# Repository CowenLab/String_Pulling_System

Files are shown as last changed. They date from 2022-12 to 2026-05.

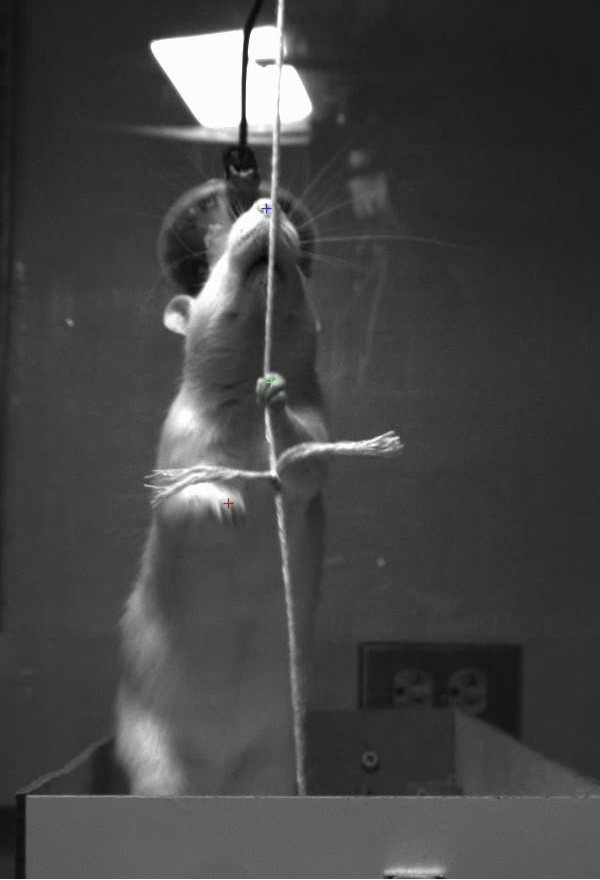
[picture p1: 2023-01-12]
Original_instructions_from_Jordan_thesis/Code/Video Processing/DeepLabCut/labeled-data/Vertical17.2_labeled/img121300.png

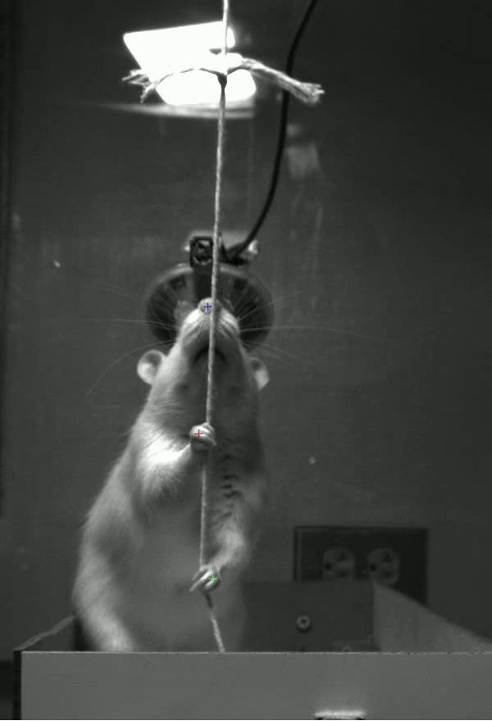
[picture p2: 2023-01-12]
Original_instructions_from_Jordan_thesis/Code/Video Processing/DeepLabCut/labeled-data/Vertical17.2_labeled/img121060.png

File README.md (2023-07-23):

# Pulling and Neural Data Analysis (PANDA) String Pulling System
Developed in the Cowen Laboratory.
See... [biorxiv](https://www.biorxiv.org/content/10.1101/2023.07.02.547431v1)

## Folders
* Hardware Manuals: Contains Manufacturer manuals of components. Currently it just has an entry for the Mako camera.
* src/arduino: Contains source code for controlling the string pulling apparatus.
** rotary_encoder: Arduino code for controlling the rotary encoder and experiment control for the single-arduino system
** rotary_encoder_two: Arduino code for controlling the rotary encoder and experiment control for the dual-arduino system (in Supplementary Information)
** experiment_control: Arduino code for the experiment control Arduino that controls the feeder in addition to tracking pull distance.. This code can handle 2 encorders (e.g., if you had 2 strings)
** experiment_control_single_encoder: As above but for a single encoder (string).
* src/matlab: Contains source code for analysis of string pulling data.
* 3d_print_and_laser_cut_files: files for printing the camera mount and pully wheels
* String_Pull_Training: Notes and logs from training specific animals on the task.
* Instructions: Additional technical instructions for building the system and for setting up the camera.
* Original_instructions_from_Jordan_thesis: Legacy data from Gianna Jordan's Masters thesis on the string pulling system.
* Videos: videos of rats performing the task.

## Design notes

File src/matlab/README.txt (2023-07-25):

This is a self-contained demo showing how to sync data with a neural recording system and how to segment front-paw video data from deep lab cut into different phases of reaching/pulling.
Make sure all files here are in your matlab path and run the demo from this directory.

The only file you need to run is SPG_demo_process_DLC_data.m

-Cowen 2023

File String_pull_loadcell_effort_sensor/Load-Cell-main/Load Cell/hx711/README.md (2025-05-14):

# HX711: Python class for the HX711 load cell

This is a very short and simple class. This lib includes three variants of the
module. One is using direct GPIO pin handling, the other uses the PIO
module of the RPI Pico. The third variant uses SPI.
Besides the class instantiation, all variants offer the same methods.
The preferred variants are GPIO and PIO, because they deal properly with the conversion
ready signal resulting in a more precise result.

## Constructor

### hx711 = HX711(clock_pin, data_pin, gain=128)

This is the GPIO constructor. data_pin and clock_pin are the pin objects
of the GPIO pins used for the communication. clock_pin must not be an input-only pin.
gain is the setting of gain and channel of the load cell amplifier.
The default value of 128 also selects channel A.

### hx711 = HX711(clock_pin, data_pin, gain=128, state_machine=0)

This is the Raspberry Pi PIO constructor. data_pin and clock_pin are the pin objects
of the GPIO pins used for the communication. 
gain is the setting of gain and channel of the load cell amplifier.
The default value of 128 also selects channel A.
The argument state_machine has to be set to different values if more than one
HX711 device is used by an application.

### hx711 = HX711(clock_pin, data_pin, spi, gain=128)

This is the SPI constructor. data_pin is the SPI MISO, clock_pin the SPI MOSI. These must be
Pin objects, with data_pin defined for input, clock_pin defined as output. They must be supplied
in addition to the spi object, even if spi uses the same  pins for miso and mosi.
spi is the SPI object. The spi clock signal will not be be used.
gain is the setting of gain and channel of the load cell amplifier.
The default value of 128 also selects channel A.

## Methods

### hx711.set_gain(gain)

Sets the gain and channel configuration which is used for the next call of hx711.read()

|Gain|Channel|
|:-:|:-:|
|128|A|
|64|A|
|32|B|

### result = hx711.read()

Returns the actual raw value of the load cell. Raw means: not scaled, no offset
compensation.

### result = hx711.read_average(times=3)

Returns the raw value of the load cell as the average of times readings of The
raw value.

### result = hx711.read_lowpass()

Returns the actual value of the load cell fed through an one stage IIR lowpass
filter. The properties of the filter can be set with set_time_constant().

### rh = hx711.set_time_constant(value=None)

Set the time constant used by hx711.read_lowpass(). The range is 0-1.0. Smaller
values means longer times to settle and better smoothing.
If value is None, the actual value of the time constant is returned.

### value = hx711.get_value()

Returns the difference of the filtered load cell value and the offset, as set by hx711.set_offset() or hx711.tare()

### units = hx711.get_units()

Returns the value delivered by hx711.get_value() divided by the scale set by
hx711.set_scale().

### hx711.tare(times=15)

Determine the tare value of the load cell by averaging times raw readings.

### hx711.power_down()

Set the load cell to sleep mode.

### hx711.power_up()

Switch the load cell on again.

## Examples

```
# Example for Pycom device, gpio mode
# Connections:
# Pin # | HX711
# ------|-----------
# P9    | data_pin
# P10   | clock_pin
#

from hx711_gpio import HX711
from machine import Pin

pin_OUT = Pin("P9", Pin.IN, pull=Pin.PULL_DOWN)
pin_SCK = Pin("P10", Pin.OUT)

hx711 = HX711(pin_SCK, pin_OUT)

hx711.tare()
value = hx711.read()
value = hx711.get_value()
```

```
# Example for micropython.org device, gpio mode
# Connections:
# Pin # | HX711
# ------|-----------
# 12    | data_pin
# 13    | clock_pin
#

from hx711_gpio import HX711
from machine import Pin

pin_OUT = Pin(12, Pin.IN, pull=Pin.PULL_DOWN)
pin_SCK = Pin(13, Pin.OUT)

hx711 = HX711(pin_SCK, pin_OUT)

hx711.tare()
value = hx711.read()
value = hx711.get_value()
```

```
# Example for micropython.org device, RP2040 PIO mode
# Connections:
# Pin # | HX711
# ------|-----------
# 12    | data_pin
# 13    | clock_pin
#

from hx711_pio import HX711
from machine import Pin

pin_OUT = Pin(12, Pin.IN, pull=Pin.PULL_DOWN)
pin_SCK = Pin(13, Pin.OUT)

hx711 = HX711(pin_SCK, pin_OUT, state_machine=0)

hx711.tare()
value = hx711.read()
value = hx711.get_value()
```

```
# Example for Pycom device, spi mode
# Connections:
# Pin # | HX711
# ------|-----------
# P9    | data_pin
# P10   | clock_pin
# None  | spi clock
#

from hx711_spi import HX711
from machine import Pin, SPI

pin_OUT = Pin("P9", Pin.IN, pull=Pin.PULL_DOWN)
pin_SCK = Pin("P10", Pin.OUT)

spi = SPI(0, mode=SPI.MASTER, baudrate=1000000, polarity=0,
             phase=0, pins=(None, pin_SCK, pin_OUT))

hx = HX711(pin_SCK, pin_OUT, spi)

hx711.tare()
value = hx711.read()
value = hx711.get_value()
```

```
# Example for micropython.org device, spi mode
# Connections:
# Pin # | HX711
# ------|-----------
# 12    | data_pin
# 13    | clock_pin
# 14    | spi clock

from hx711_spi import HX711
from machine import Pin

pin_OUT = Pin(12, Pin.IN, pull=Pin.PULL_DOWN)
pin_SCK = Pin(13, Pin.OUT)
spi_SCK = Pin(14)

spi = SPI(1, baudrate=1000000, polarity=0,
          phase=0, sck=spi_SCK, mosi=pin_SCK, miso=pin_OUT)

hx = HX711(pin_SCK, pin_OUT, spi)

hx711.tare()
value = hx711.read()
value = hx711.get_value()
```

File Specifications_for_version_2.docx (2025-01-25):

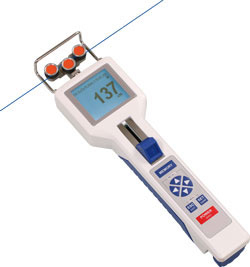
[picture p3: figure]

- Integrated tensiometer that does not add much string resistance. Wire resistance design.
  - https://www.futek.com/applications/Wire-Tension-Meter
  - https://www.futek.com/applications/Wire-Tension-Measurement
  - DTS Hand-Held Digital Tension Meter
- Capacity for 2 strings side-by-side.
- 2 levers also to the side.
- Food port integrated. Solenoid.
- Laser sensors for approach and food port.
- Integrated tracking with camera.
- Arduino or pico?
- Clear TTLs for sync with neural data.
- Integration with 28V Med Associates system.- I want an independent interface that connects med associates levers to any Arduino—just send out 5V pulses to extend/retract and just get 5V pulses (isolated) for when a lever is pressed. General purpose and will plug into any med associates lever system – one per lever – nothing complicated. Maybe smaller isolators? Noise Free.
- Simple laser-cut holder for string. All designs in Fusion 360.
- Simple and documented code.
- Ultimately – would like 3 such systems.

Other

- A way to incorporate a ‘ratchet’ so that the string only turns in one direction to train a novel movement direction.
- A way to angle the string?

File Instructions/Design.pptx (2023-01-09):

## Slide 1

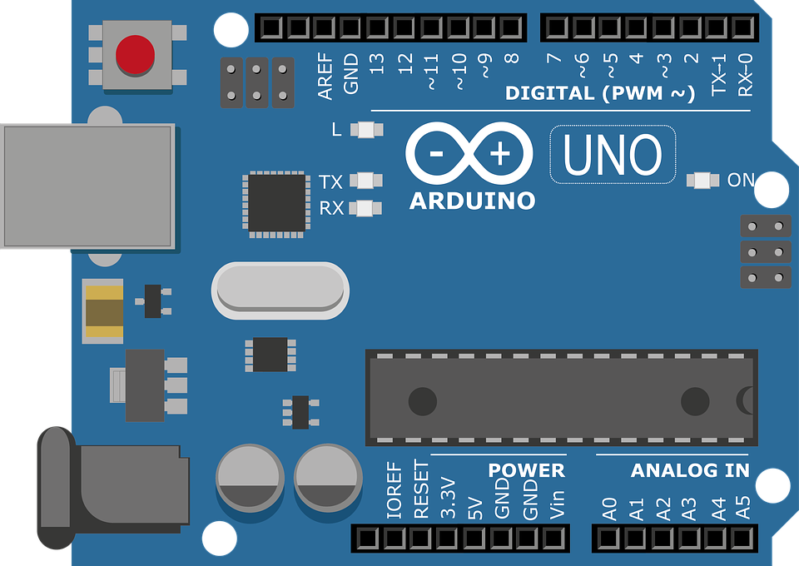
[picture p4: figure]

Picture from the Arduino website.
Dual Arduino setup

Experiment Control Microcontroller

Rotary Encoder Microcontroller

To Feeders

12V Source

Feeder Relay

7-12V source

USB to PC

7-12V source

Acquisition System

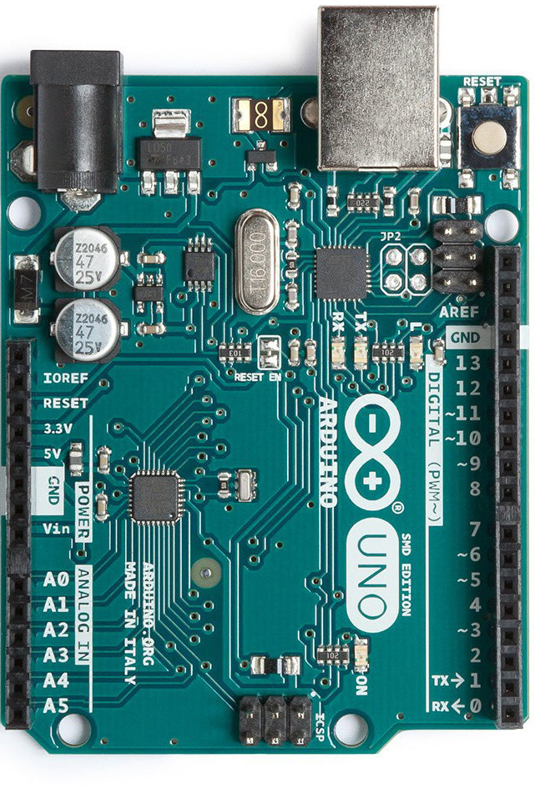
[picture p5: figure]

5V
GND

TO: Control Arduino AND
Acquisition Computer

12) Feeder Button

11) Rot2 B CCW
10) Rot2 B CW
9) Rot1 A CCW
8) Rot1 A CW

FROM: Rotary Encoder Arduino

2,3) Sound Shield

11) Rot2 B CCW
10) Rot2 B CW
9) Rot1 A CCW
8) Rot1 A CW

TO: Relays

14) Relay1
15) Relay2

TO/FROM: Rotary Encoders

5V
GND

5) Rot2 B
4) Rot1 B
3) Rot2 A
2) Rot1 A

FROM: Rotary Encoders

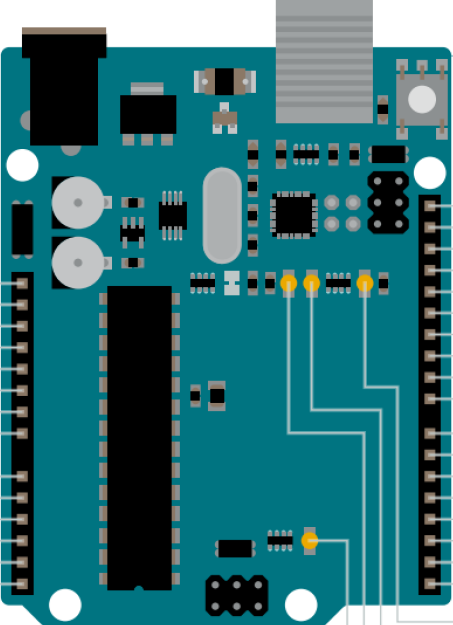
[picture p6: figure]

18) Clock
19) Signal

TO: Data Acquisition System

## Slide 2

Picture from the Arduino website.
Single Arduino setup

Experiment Control Microcontroller

To Feeders

12V Source

Feeder Relay

7-12V source

USB to PC

5V
GND

TO: Relays

14) Relay1
15) Relay2

5) Rot2 B
4) Rot1 B
3) Rot2 A
2) Rot1 A

FROM: Rotary Encoders

18) Clock
19) Signal

TO: Data Acquisition System

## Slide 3

This is from their datasheet so probably legit to use

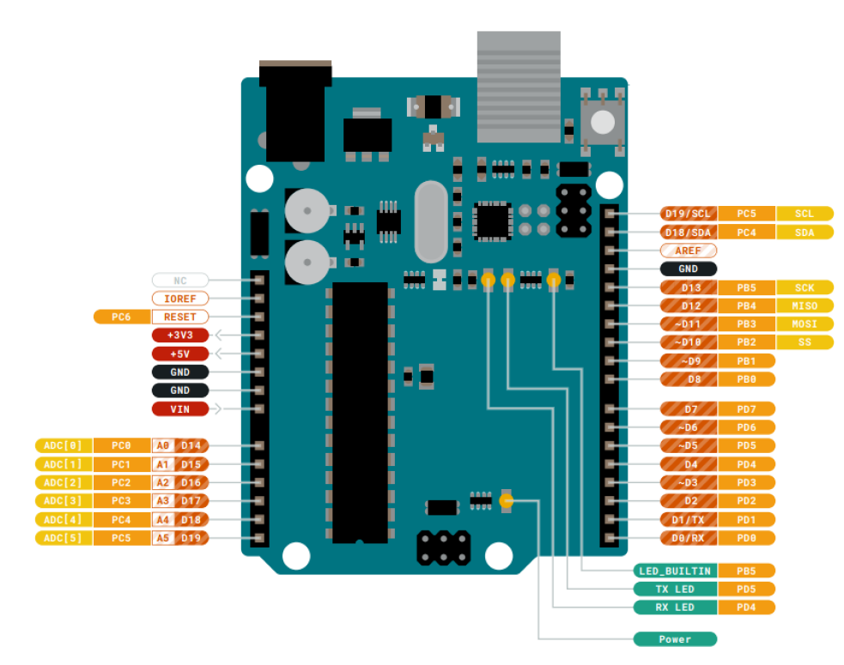
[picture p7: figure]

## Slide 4

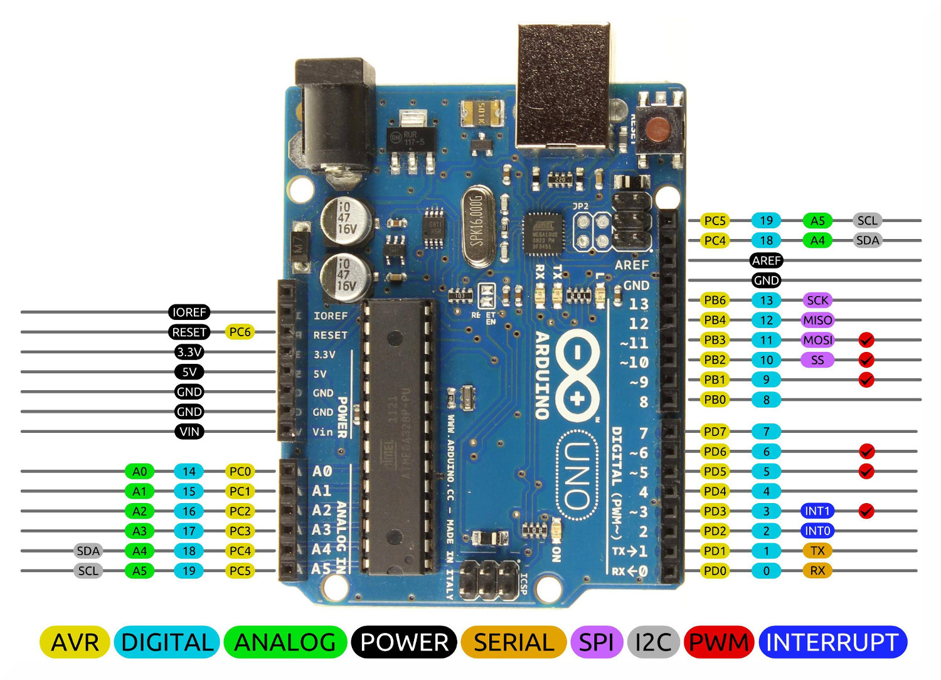
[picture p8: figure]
Arduino Uno R3 Pinouts Chart - IX23

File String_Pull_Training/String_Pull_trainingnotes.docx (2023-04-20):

431 platform length documentation

- Stopped at length 3 – what happened to the other session lengths?

Input actual distances – no longer using the numeric coding

General

- All inputs (besides “Notes”) need to have numerical values; no characters

For “SyringeShapingBouts”

- Only document number of bouts IF the syringe is being used to guide the rat (do not use this on the Arduino automated shaping)
- When syringe shaping, you only need to input one row – this will essentially show the number of guided attempts
  - (BUT be sure to input individual rows for each bout on Arduino shaping!!)
- Do not input a length being pulled on syringe shaping – during syringe shaping, the length is arbitrary and we don’t know the exact length the rat is pulling

Documenting each pull bout

- E.g., if doing platform on length 1 three times successfully, document each of the three bouts:

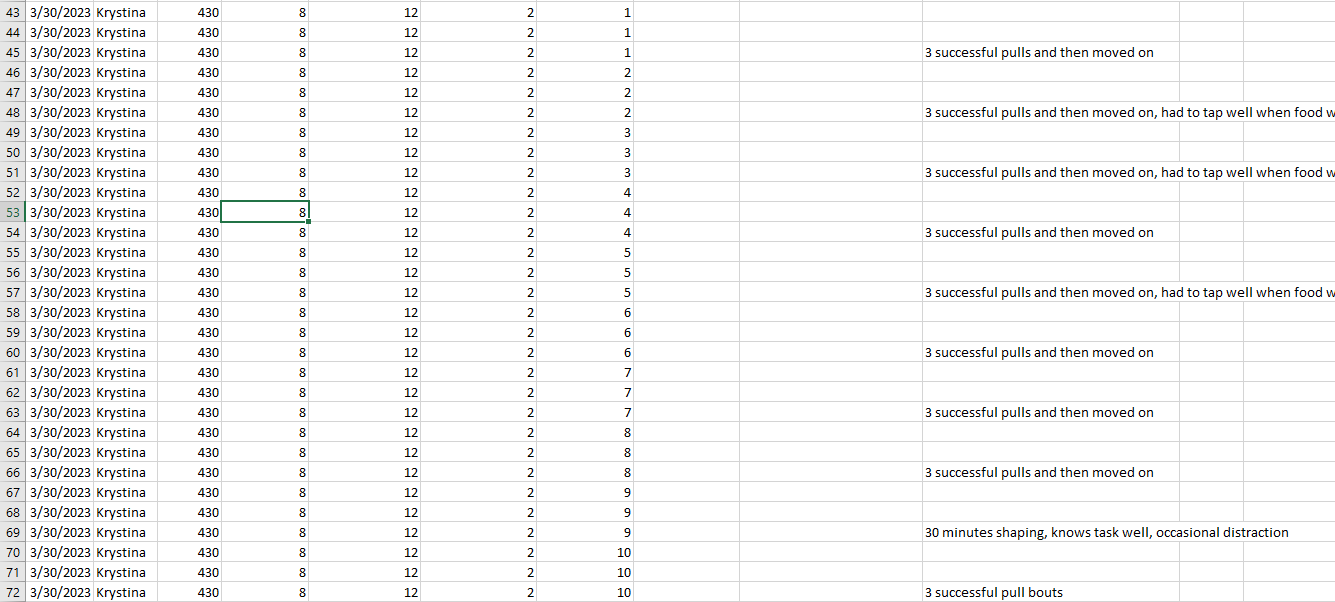
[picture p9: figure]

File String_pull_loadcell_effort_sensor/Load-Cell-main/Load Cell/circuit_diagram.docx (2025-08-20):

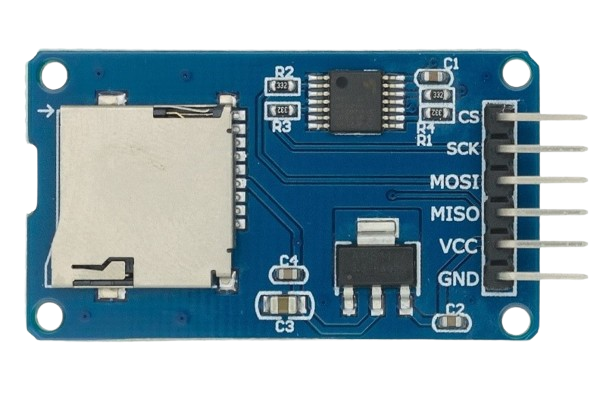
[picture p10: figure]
How to Use Micro SD Card Module: Pinouts, Specs, and Examples | Cirkit Designer
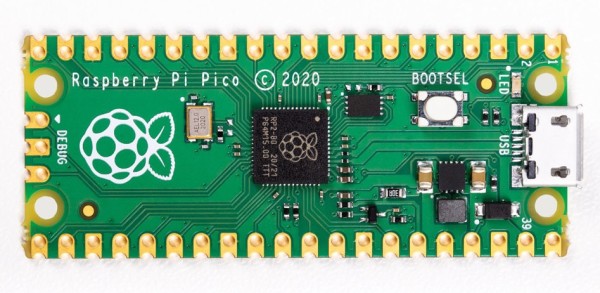
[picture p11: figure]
Pico Power: Get to Know the Raspberry Pi Pico Board and RP2040 | Elektor Magazine

GND pin 13

Yellow – PWM sig pin 12, GP9

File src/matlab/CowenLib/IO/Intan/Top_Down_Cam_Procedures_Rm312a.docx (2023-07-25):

# Top-Down camera video recording procedures ROOM 312A.

# Preliminaries

- Make sure cameras and Intan system are plugged in and that there is a headstage plugged into the Intan system.

# INTAN PC:

1. Start Intan, load the correct settings, start acquisition (NOT RECORDING), and view the digital in input. This will allow you to verify that the proper TTL signals from the cameras and feeder are being registered by the INTAN system.

# Top Cam PC:

1. On CAM PC: Start StreamPix 8 Lite and choose the AVT Vimba config. This is paid for software so there has to be a license on the computer you are using (e.g., if you use this on another computer, it will not work). IT’s not too bad – around $450. There may be something out there for free, but I have not found anything better.
2. Read the manual and experiment. Get to know this software and the code. When you start up, you should see something like this… If the camera is connected, and you hit, Live (upper left) then you should see the video.

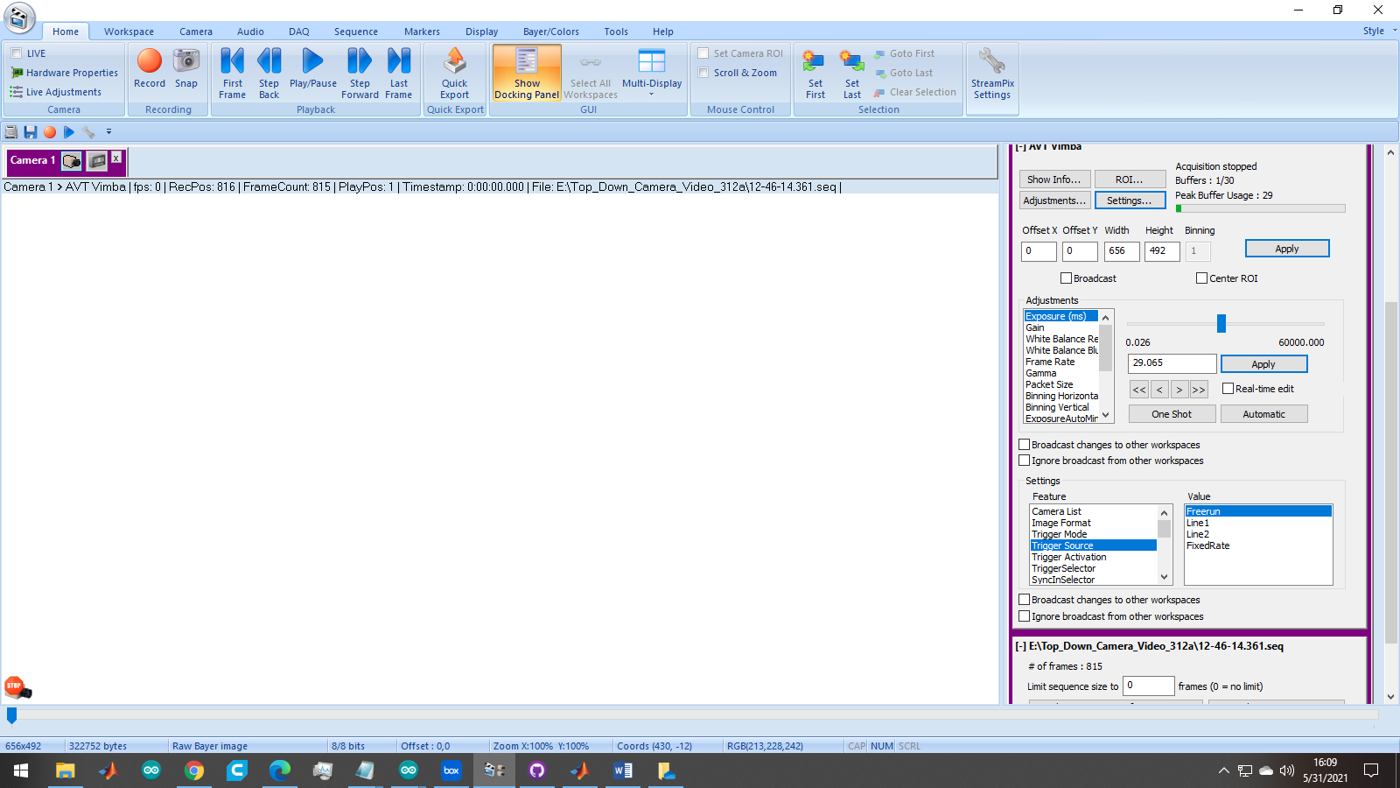
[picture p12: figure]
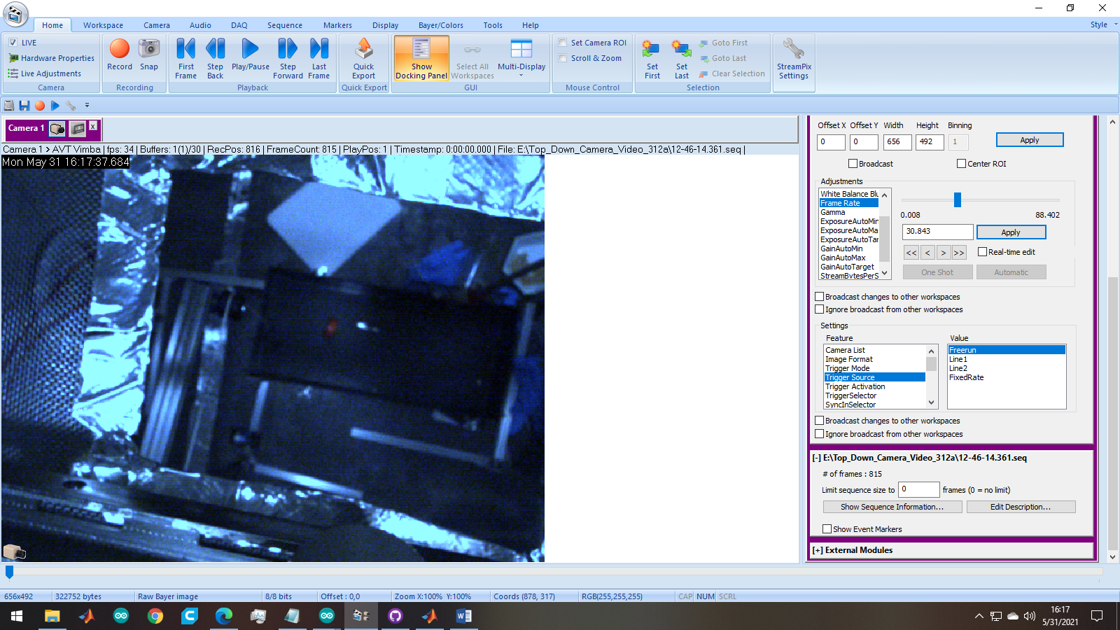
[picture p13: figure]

3. Ensure the save directory is correct. This is convoluted. You need to go to the little icon in the upper right (StreamPix settings) and then to workspace.
  a. Make sure the working folder is correct (see below)
  b. Make sure the AVI is set to NorPix h264 encoder (or no compression).

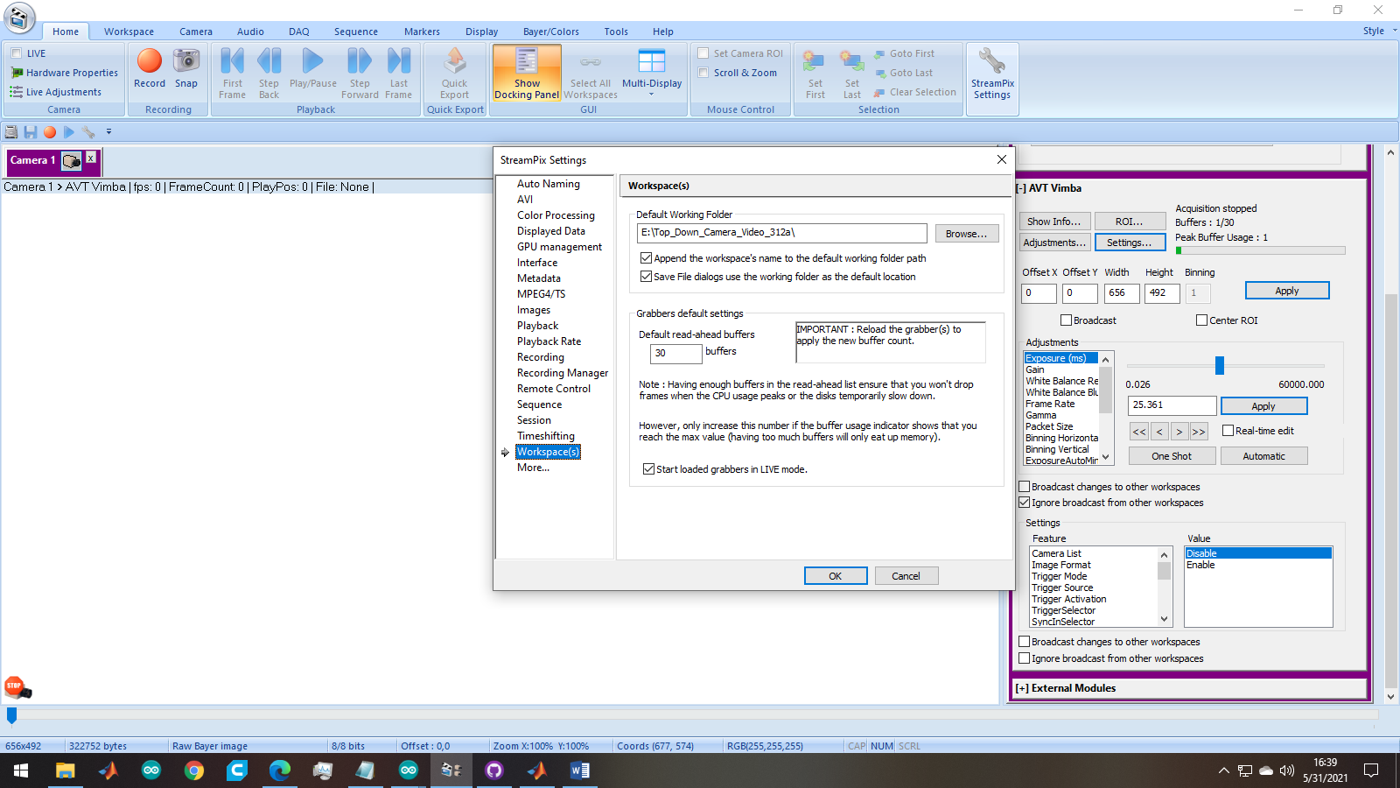
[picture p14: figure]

4. Ensure adjustments and settings (on right panel – there is a separate pane for adjustments and settings) are correct (these need to be fine tuned):
  a. Adjustments
    i. Exposure: 29.065
    ii. Gain: 27.000
    iii. ROI: 0 0 656 492
  b. Settings
    i. Trigger Mode: On
    ii. Trigger Source: Free Run
    iii. Image Format: BayerRG8
    iv. Sync Out Source: Exposing
5. Check the frame rate. It needs to be >= 30 fps. If not, something should be adjusted.
6. DO NOT HIT RECORD FOR ANY OF THIS – ONLY ONCE INTAN IS RECORDING.
7. Check to be sure the color of the red LED or red mark is very clear.
8. Look back at the INTAN system. Look at Dig In for input 10. You should see TTLs coming in. If you adjust the frame rate on the camera computer, then these TTL should change accordingly. Feel free to test this. For TTLs to come in, you need to have LIVE clicked in NorPix. If you unclick, the TTLs will go away.
9. Once you are all satisfied that things are set up correctly, UNCLICK LIVE AND GO BACK TO INTAN.
10. When everything on the Intan system and other devices (e.g., the front camera) are ready to go, then start recoding on the intan system.
11. Go back to the top down camera system.
12. Hit Record. (nothing should appear on the screen or on the Intan).
13. Hit Live (now the pulses should appear and the video should appear on the screen.
14. WHEN DONE AND BEFORE YOU STOP RECORDING ON THE INTAN SYSTEM: Stop record on the video acquisition system. Check the file – make sure it was saved.
15. Back up data and put in same folder as INTAN data.

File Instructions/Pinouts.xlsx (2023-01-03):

Panel Pinout |  | See the ppt - more clear I think
Rotary Encoder 1 and 2 |  |  |  |  | External To Acquistion System
Pin | Function | Color | Code |  | 1 | GND | Black
1 | GND | Black | RotGND | RotGND | 2 | Rot Enc 1 Tic | White | Could do short tics for CW and long tics for CCW so that only one line.
2 | 5V | Red | Rot5V | Rot5V | 3 | Rot Enc 1 Dir
3 | TicA | Blue | Rot1TicA | Rot2TicA | 4 | Rot Enc 2 Tic
4 | TicB | White | Rot1TicB | Rot2TicB | 5 | Rot Enc 2 Dir
 |  |  |  |  | 6 | Maze event |  | single pulse = Feed, double = Sensor 1, triple, Sensor 2.
From Input from Maze
1 | GND | Black
2 | 5V | Red
3 | From detector 1
4 | From detector 2
5+ | reserved
 |  |  |  |  | Arduino 1 (Rotary Encoder Arduino)
To Feeder |  |  |  |  | INPUT |  |  | Maze Event
1 | GND from 12V |  |  |  | Arduino Pin (0 based) |  |  | 8 | Rot1CWTic | To Arduino 2 and Digital Out
2 | Sig (12V) Feed 1 |  |  |  | 2 | Rot1TicA |  | 9 | Rot1CCWTic
3 | Sig (12V) Feed 2 |  |  |  | 3 | Rot2TicA |  | 10 | Rot2CWTic
4+ | reserved |  |  |  | 4 | Rot1TicB |  | 11 | Rot2CCWTic
 |  |  |  |  | 5 | Rot2TicB
 |  |  |  |  | GND | RotGND
 |  |  |  |  | 5V | Rot5V
 |  |  |  |  | Arduino 2 (Experiment Control Arduino)
 |  |  |  |  | INPUT |  |  | OUTPUT
 |  |  |  |  | Arduino Pin (0 based) |  |  | 14 | General_IO1 |  | Signal | Pulses come in sets of 4 so 2^4 combos which should be enough
 |  |  |  |  | 8 | Rot1_CW_Tic |  | 15 | General_IO2 |  | Timing pulse | one pulse for each digital signal
 |  |  |  |  | 9 | Rot1_CCW_Tic |  | 16 |  |  | Code
 |  |  |  |  | 10 | Rot2_CW_Tic |  | 11 | Rot2CCWTic |  | 1 | Feeder 1 triggered
 |  |  |  |  | 11 | Rot2_CCW_Tic |  |  |  |  | 2 | Feeder 2 triggered
 |  |  |  |  |  |  |  |  |  |  | 3 | Sensor 1 tripped
 |  |  |  |  |  |  |  |  |  |  | 4 | Sensor 2 tripped
 |  |  |  |  |  |  |  |  |  |  | 5 | Sound 1 onset
 |  |  |  |  |  |  |  |  |  |  | 6 | Sound 2 onset

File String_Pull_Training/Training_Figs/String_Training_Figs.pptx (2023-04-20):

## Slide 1

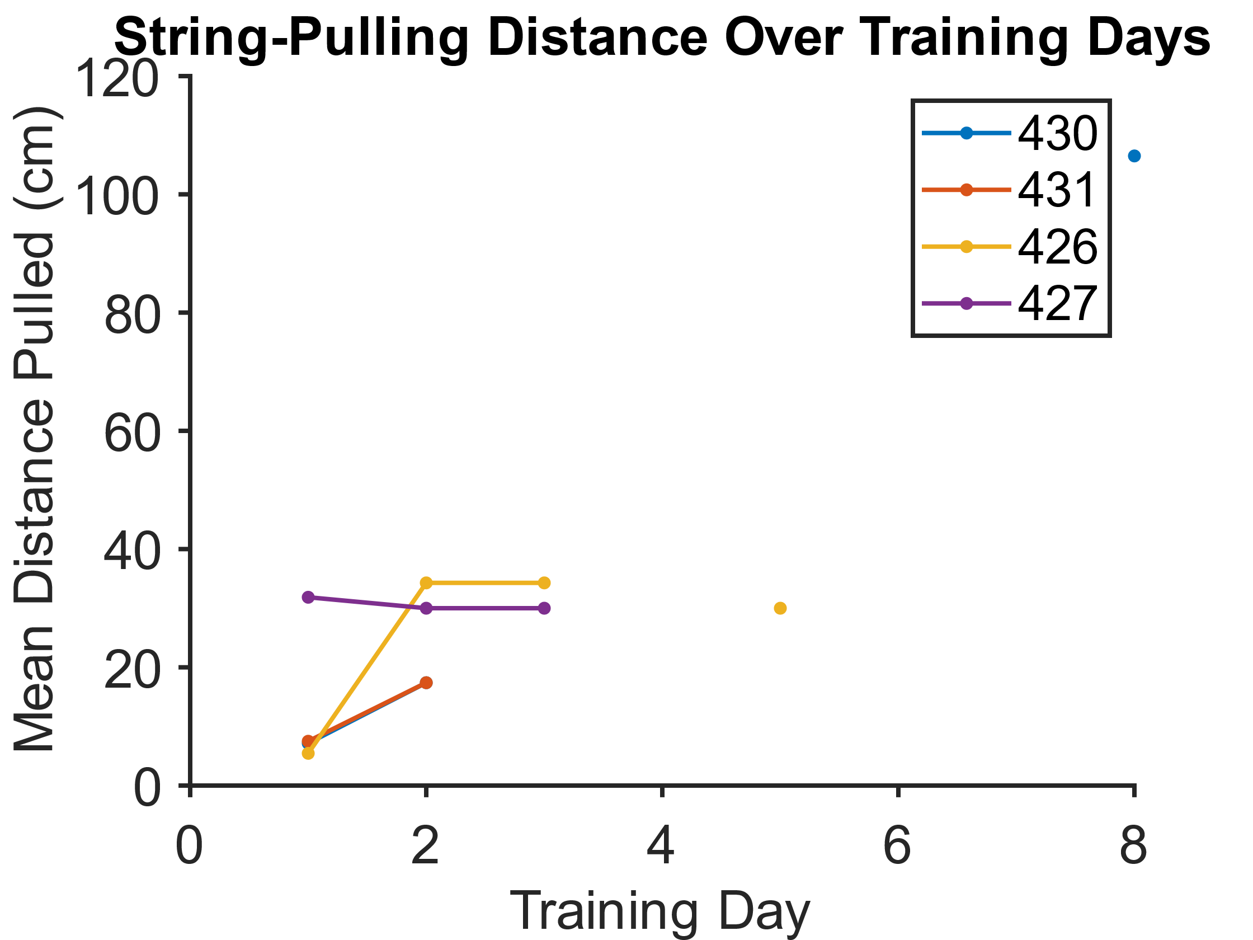
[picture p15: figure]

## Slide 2

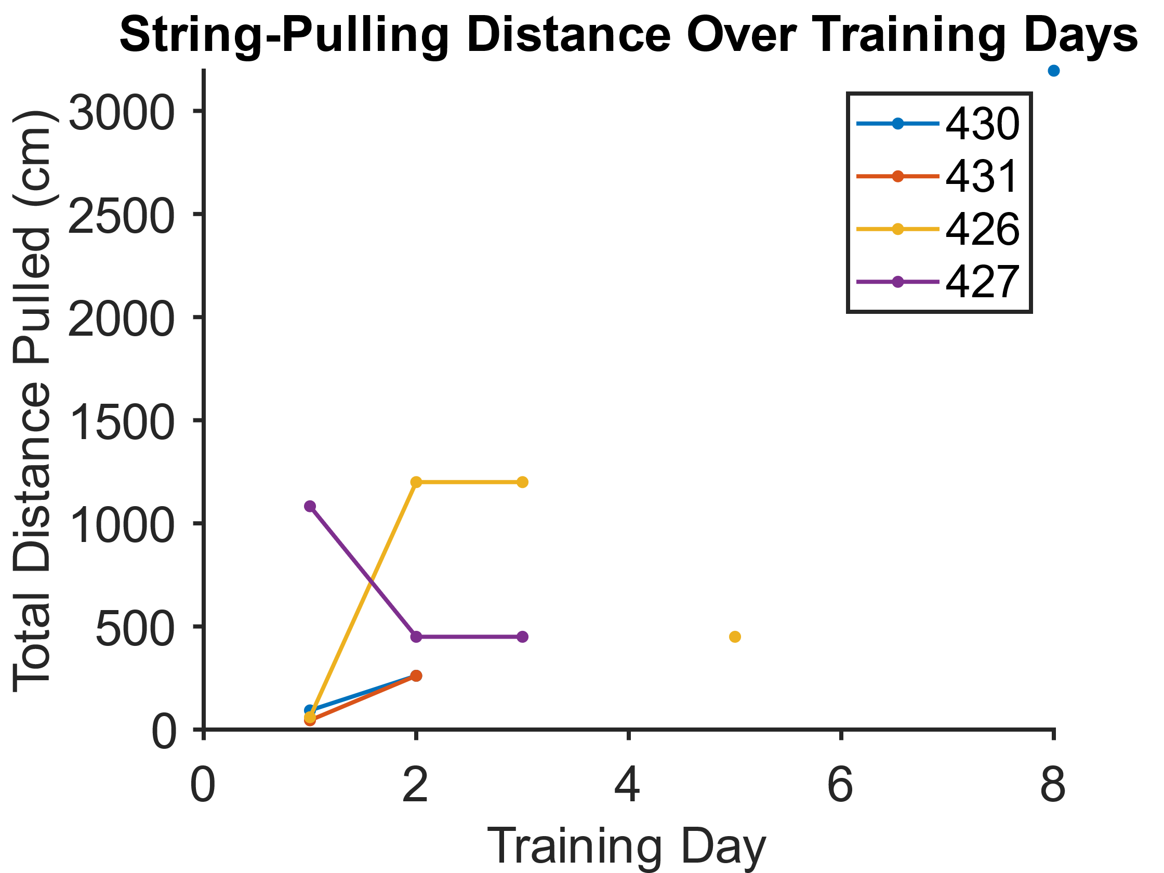
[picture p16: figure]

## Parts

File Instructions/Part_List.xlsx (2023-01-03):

Table 1 - Parts List
Component | Manufacturer | Part No. | Website
Electronic Components
Mako U-130b Camera* (option1) | Allied vision | Mako U-130b | https://cdn.alliedvision.com/fileadmin/pdf/en/Mako_U-130_DataSheet_en.pdf
Alvium 1800 U-040 (option 2) | Allied vision | Alvium 1800 U-040 | https://www.alliedvision.com/en/products/alvium-configurator/alvium-1800-u/040-1/#_configurator
LED Panel | Viltrox | L116T | https://www.amazon.com/VILTROX-L116T-3300K-5600K-Temperature-Brightness/dp/B07D8TTFSR
Ring Light, 10" | UBeeSize | UBeeSize Ring Light | https://www.amazon.com/10-Extendable-UBeesize-Ringlight-Compatible/dp/B07QFV72LK
Arduino Uno | Arduino | Arduino Uno Rev3 | https://store-usa.arduino.cc/collections/boards/products/arduino-uno-rev3
Arduino Mega | Arduino | Mega 2560 Rev3 | https://store.arduino.cc/usa/mega-2560-r3
Rotary Encoder | BQLZR | BQLZR 600P/R | https://www.amazon.com/gp/product/B00UTIFCVA/ref=ppx_yo_dt_b_search_asin_title?ie=UTF8&psc=1
Digital Distance Sensor 5cm | Pololu | 4050 | https://www.pololu.com/product/4050
Project Box 12.2 x 11.2 x 4.5" | Zulkit | NA | https://www.amazon.com/gp/product/B08NGGMKC3/ref=ppx_yo_dt_b_search_asin_image?ie=UTF8&th=1
Solenoid Valve 1/4" | STC Valve | 2P025-1/4 | https://www.stcvalve.com/Solenoid-Valve-Specifications-2P025-Series.htm
Panel Mount Aviation Connectors | Hilitchi | 8541770567 | https://www.amazon.com/gp/product/B07F5B5LLX/ref=ppx_yo_dt_b_search_asin_title?ie=UTF8&th=1
Physical Apparatus
T-slot nuts | Sutemribor | STBR-T-luomu-160P-kit | https://www.amazon.com/gp/product/B07FPLZXTF/ref=ppx_yo_dt_b_search_asin_image?ie=UTF8&psc=1
Cotton Twine #16 [CHECK] | Ace Hardware | C8016B0008AC | https://www.acehardware.com/departments/hardware/chain-and-rope/ropes/7373707
3D printer wheel with bearings | SeekLiny | NA | https://www.amazon.com/dp/B09SSWZG82?ref=ppx_yo2ov_dt_b_product_details&th=1
Extruded Aluminum (20/20) | Zyltech | EXT-2020-REG-1000-10X | https://www.amazon.com/gp/product/B07F6R2Z99/ref=ppx_yo_dt_b_search_asin_title?ie=UTF8&psc=1
90° Corner Bracket | LANIAKEA | NA | https://www.amazon.com/gp/product/B08NXGV1YH/ref=ppx_yo_dt_b_search_asin_title?ie=UTF8&psc=1
Neural Data Acquisition Systems
Intan USB Interface Board (option 1)* | Intan Technologies | NA | https://intantech.com/RHD_USB_interface_board.html
RHD Recording Controller (option 2) | Intan Technologies | NA | https://intantech.com/recording_controller.html
*Specific Model Discontinued. In these cases, an updated part is provided as a second option.
The above list does not include connonly available parts such as nuts and bolts, wire/cable, header connectors, standoffs, etc…
CowenLab/String_Pulling_System (github.com) (https://github.com/CowenLab/String_Pulling_System)

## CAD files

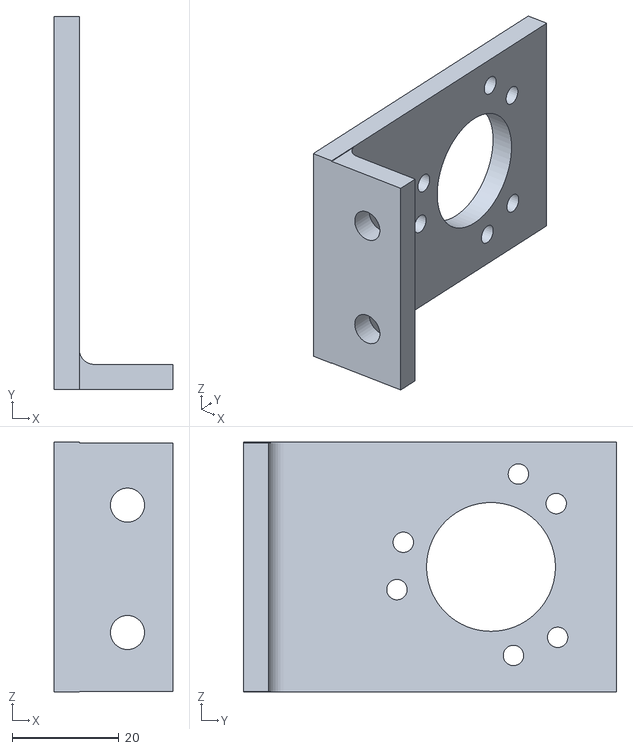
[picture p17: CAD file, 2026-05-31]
3d_print_and_laser_cut_files/encoder_mount_for_human_pull.stl
22.3 x 70.0 x 46.9

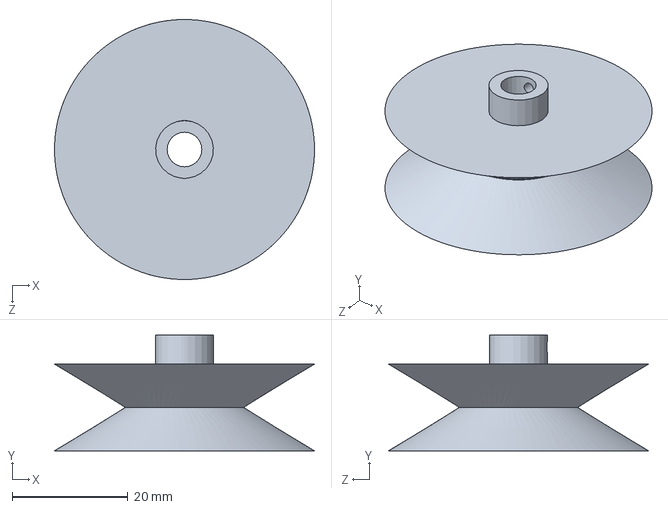
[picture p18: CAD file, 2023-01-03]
Original_instructions_from_Jordan_thesis/3D Files/Rot Encoder Wheel.SLDPRT
45.0 x 20.0 x 45.0 mm

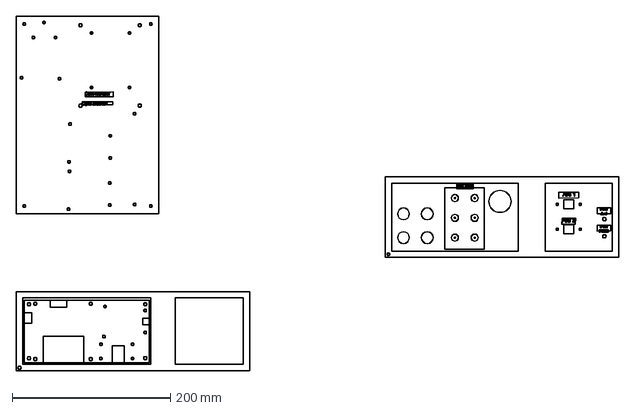
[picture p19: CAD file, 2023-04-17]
3d_print_and_laser_cut_files/front_panels_for_exp_control.dxf
761.5 x 448.2 mm

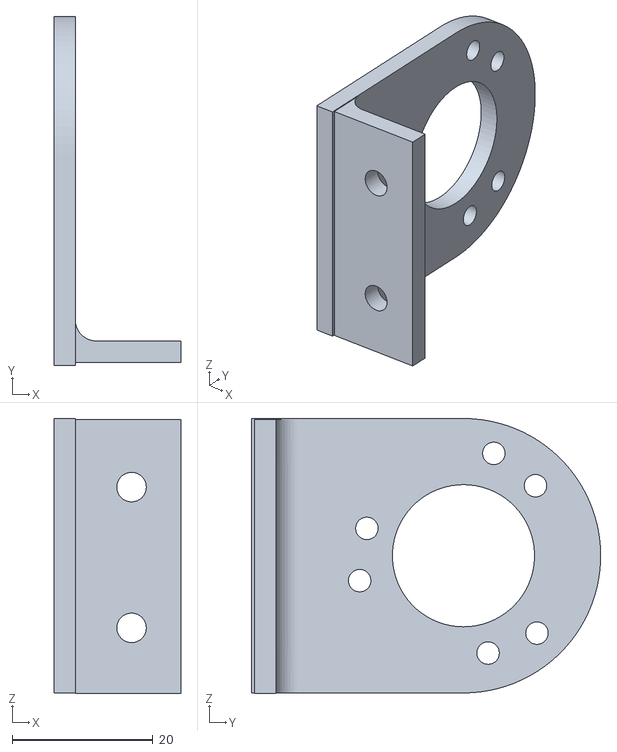
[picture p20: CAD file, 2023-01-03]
Original_instructions_from_Jordan_thesis/3D Files/encoder_mount.stl
18.0 x 49.6 x 39.1

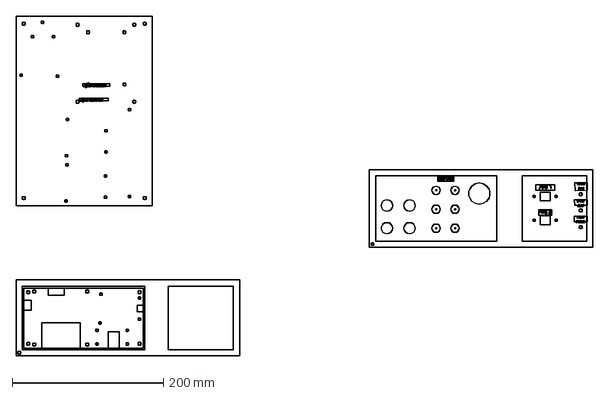
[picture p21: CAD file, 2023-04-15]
3d_print_and_laser_cut_files/mount_for_controllers.dxf
761.5 x 448.2 mm

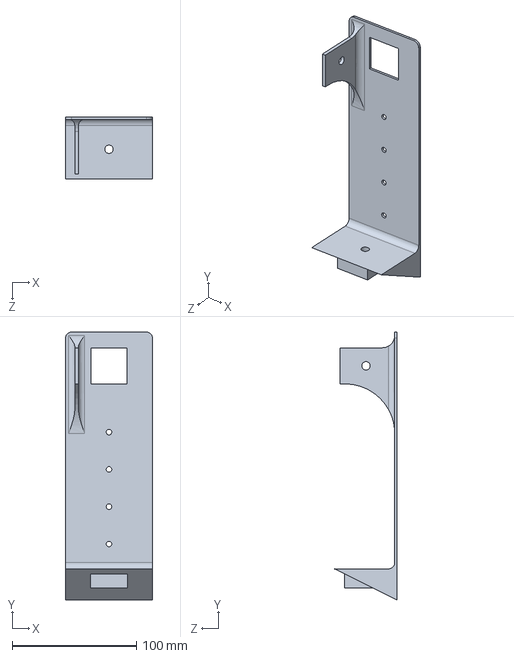
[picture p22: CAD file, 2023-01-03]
Original_instructions_from_Jordan_thesis/3D Files/camera mount.SLDPRT
70.0 x 215.5 x 50.2 mm

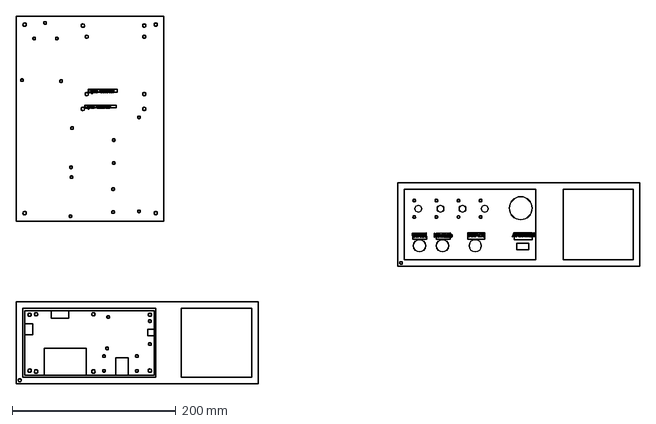
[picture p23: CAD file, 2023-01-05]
3d_print_and_laser_cut_files/standoff.dxf
760.5 x 448.2 mm

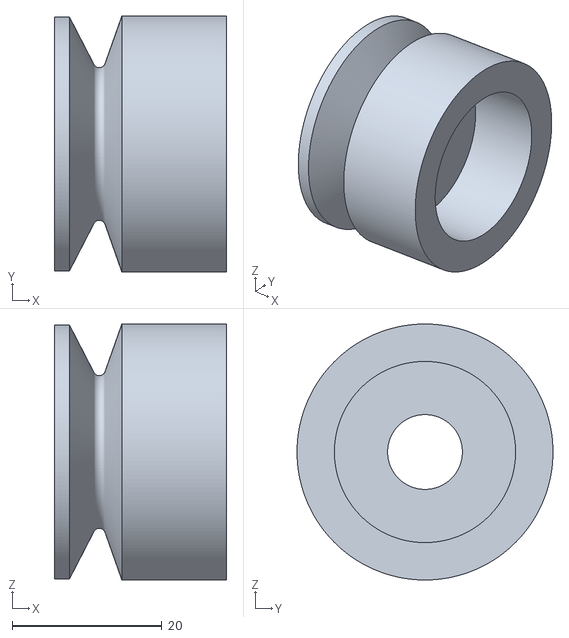
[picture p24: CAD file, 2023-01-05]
3d_print_and_laser_cut_files/Wheel4.stl
23.0 x 34.2 x 34.2

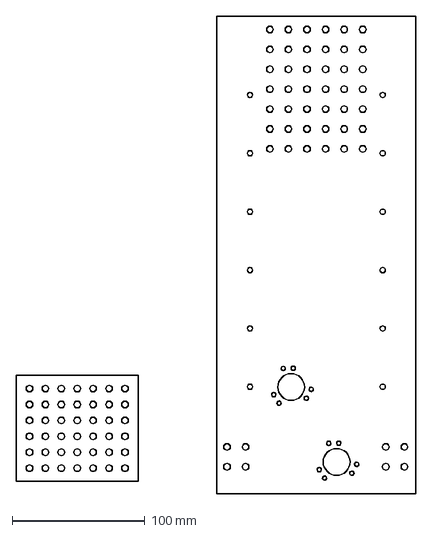
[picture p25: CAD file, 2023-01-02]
3d_print_and_laser_cut_files/string_frame.dxf
301.2 x 360.0 mm

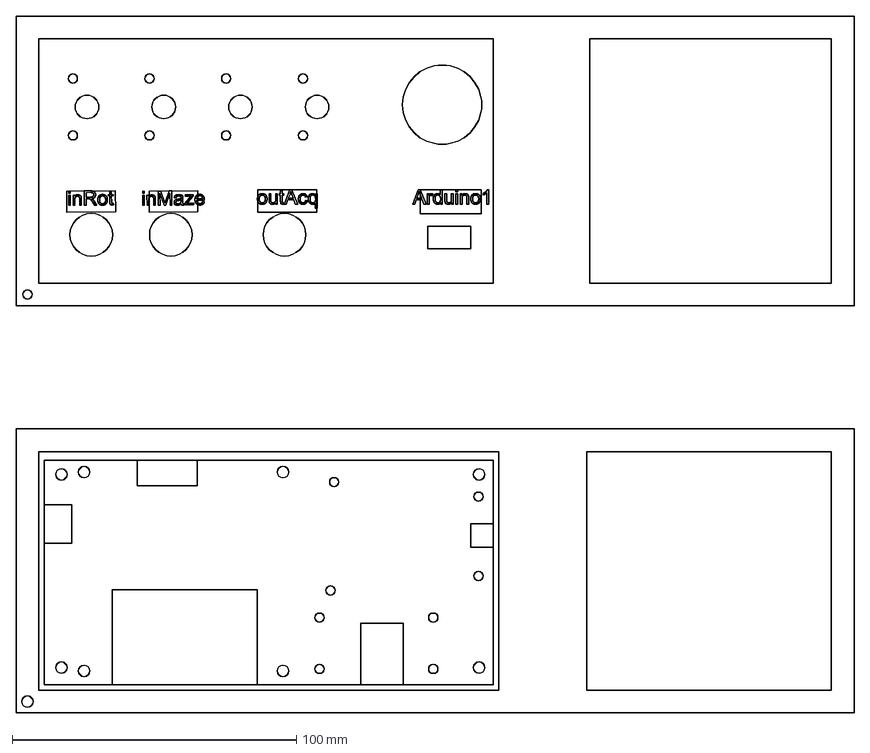
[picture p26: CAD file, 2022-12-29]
3d_print_and_laser_cut_files/infinite_string.dxf
295.0 x 245.3 mm

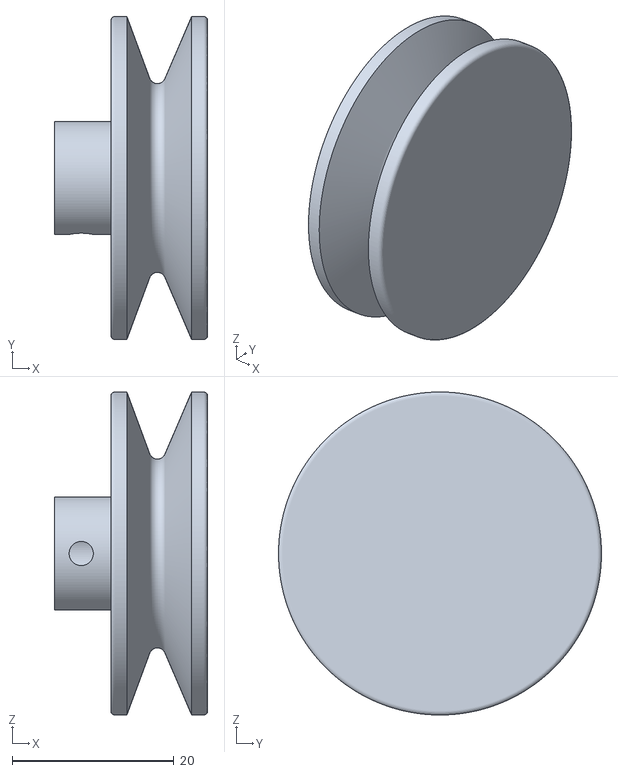
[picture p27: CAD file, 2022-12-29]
3d_print_and_laser_cut_files/Wheel1.stl
19.0 x 40.0 x 40.0

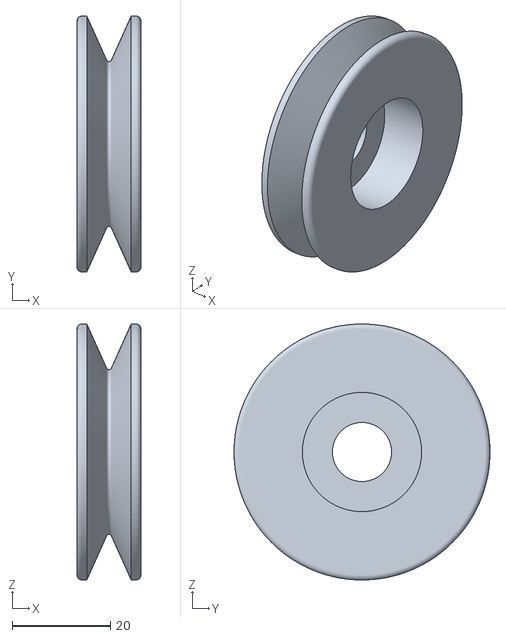
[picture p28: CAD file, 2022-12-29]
3d_print_and_laser_cut_files/Wheel2.stl
13.0 x 52.0 x 52.0

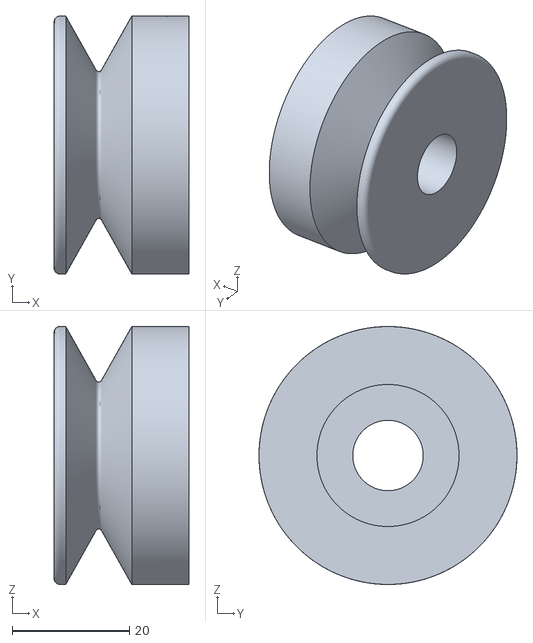
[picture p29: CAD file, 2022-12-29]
3d_print_and_laser_cut_files/Wheel3.stl
23.0 x 44.0 x 44.0

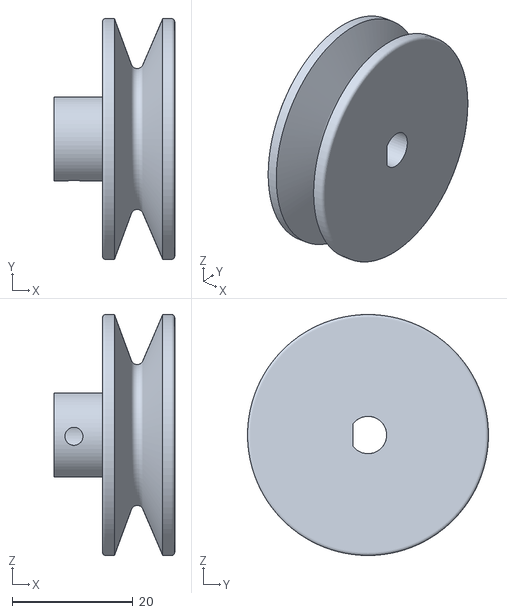
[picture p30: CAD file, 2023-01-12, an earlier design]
Original_instructions_from_Jordan_thesis/3D Files/Old files/encoderwheel.stl
20.0 x 40.0 x 40.0

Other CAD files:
Original_instructions_from_Jordan_thesis/3D Files/Old files/regular_wheel.stl
3d_print_and_laser_cut_files/encoder_mount.f3d
Original_instructions_from_Jordan_thesis/3D Files/Rot Encoder Wheel.STL
Original_instructions_from_Jordan_thesis/3D Files/camera mount.STL

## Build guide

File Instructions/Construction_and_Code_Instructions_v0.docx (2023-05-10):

## Arduino-RE controller

Input to Arduino-RE from controller Arduino-Control:

1) 5V
2) GND

Output to Arduino-Control from Arduino-RE:

1) Tic pulse. Short .5ms pulse for each tic. The degree rotation for each tic can be set up in the Arduino code.
2) Turn direction: high for clockwise, low for counter clockwise. It stays at the last state until it changes.
3) [optional] Active: ? not sure if I need this. Would just show high if the animal is pulling saving some processing on the Arduino-control side of things. Would go high when tics are detected and stay high for say 100ms.

Input from the Rotary encoder.

1) Green = A phase,
2) White = B phase,
3) Red = Vcc positive power supply 5-24V
4) Black = V0 ground, please wire as above.
5) Another metal shielding mesh layer is anti-interference. This can be shorted to black and also go in shielding around any cabling.

We have the 600 pulse/rotation. It’s a bit much so we have an Arduino in between to do some of the processing.

How to detect the direction and code.

///////////////////////////////////////////////////////

// Code to sense a rotary encoder.

// LPD3806 – Optical Rotary Encoder

//

///////////////////////////////////////////////////////

// Cowen and also code from

// https://www.instructables.com/Tutorial-of-Rotary-Encoder-With-Arduino/

// https://www.circuitschools.com/rotary-encoder-with-arduino-in-detail-with-example-codes/

///////////////////////////////////////////////////////

#define encoder0PinA 2

#define encoder0PinB 3

#define outPinTic 4

#define outPinDirection 5

#define TTL_DELAY_MS 2

#define TICS_PER_SIGNAL 100

int encoderPos = 0;

int tempEncoderPos = 0;

int ticCountCW = 0;

int ticCountCCW = 0;

void setup() {

Serial.begin(115200);

pinMode(encoder0PinA, INPUT_PULLUP);

pinMode(encoder0PinB, INPUT_PULLUP);

pinMode(outPinTic, OUTPUT);

pinMode(outPinDirection, OUTPUT);

digitalWrite(outPinTic,0);

digitalWrite(outPinDirection,0);

attachInterrupt(0, doEncoder, RISING); // Must be rising

}

int lastValRotary;

int valRotary;

int send_signal = 0;

void loop() {

if (send_signal > 0 ){

send_signal = 0;

digitalWrite(outPinTic,HIGH);

delay(TTL_DELAY_MS);

digitalWrite(outPinTic,LOW);

if(valRotary>lastValRotary) {

digitalWrite(outPinDirection, HIGH);

Serial.print(" CW ");

// Serial.print(ticCountCW);

}

if(valRotary<lastValRotary) {

digitalWrite(outPinDirection, LOW);

Serial.print(" CCW ");

//Serial.print(ticCountCCW);

}

Serial.print(" re ");

Serial.print(valRotary);

Serial.println(" ");

}

lastValRotary = valRotary;

}

void doEncoder()

{ // Only runs on rising edge

if (digitalRead(encoder0PinA) != digitalRead(encoder0PinB))

{

encoderPos++;

tempEncoderPos++;

//ticCountCW++;

//ticCountCCW = 0;

}else{

encoderPos--;

tempEncoderPos--;

// ticCountCCW++;

// ticCountCW = 0;

}

valRotary = encoderPos;

if (abs(tempEncoderPos) >= TICS_PER_SIGNAL){

tempEncoderPos = 0;

send_signal = 1;

}

}

## Rotary Encoder

Pinout:

Green = A phase,

White = B phase,

Red = Vcc positive power supply 5-24V

Black = V0 ground, please wire as above.

Another metal shielding mesh layer is anti-interference. This can be shorted to black and also go in shielding around any cabling.

We have the 600 pulse/rotation. It’s a bit much so we have an Arduino in between to do some of the processing.

AB two-phase output rectangular orthogonal pulse, the circuit output is NPN open collector output type, this output type can be directly connected with single-chip microcomputer or PLC with internal pull-up resistor, such as 51 single-chip or Mitsubishi PLC (PLC input mode Should be connected to the switch to 0V function), Note: If the encoder is not connected to the device, the oscilloscope cannot be directly oscillating (the open collector output has no voltage output when there is no pull-up resistor). Two pull-up resistors are added to the two-phase output of the AB;

Uses:

Used to measure the rotation speed, angle, acceleration and length of an object.

Scope of application:

It is suitable for intelligent control of various displacement change measurement, automatic fixed length automatic suede machine, steel fixed length cutting controller, civil height measuring human body scale, college student competition robot, etc.

Features:

It has the advantages of small size, light weight, convenient installation and high cost performance.

Note:

A phase and B phase output lines must not be connected directly to VCC, otherwise, the output three-stage tube will be burned.

# Connecting the camera to the neural recording system

The Matlab Image Acquisition Toolbox Graphical User Interface (GUI) and a second circuit were used to configure the camera to send a TTL pulse to the Intan data acquisition system (Intan Technologies, Los Angeles, California, United States) every time a frame was exposed. This allowed the timing of each frame to be aligned with the recorded neural activity. This circuit consisted of an open collector trigger from the camera and a pull up resistor to process the signal for triggering the Intan system. After collection, video information was processed by DeepLabCut (Mathis et al., 2018) and custom Matlab code (github.com/GiaJordan/Behavior_Quantification).

NOTE: Open collector means no voltage goes out – do you need a pullUP resistor? According to https://en.wikipedia.org/wiki/Open_collector this is true ( I was mistakenly using a pulldown resistor)

Looks like the pullup can be in the range of 3KOhm to 6KOhm.

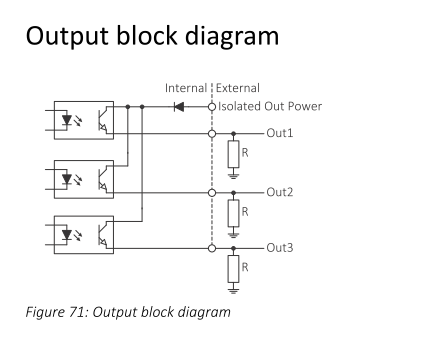
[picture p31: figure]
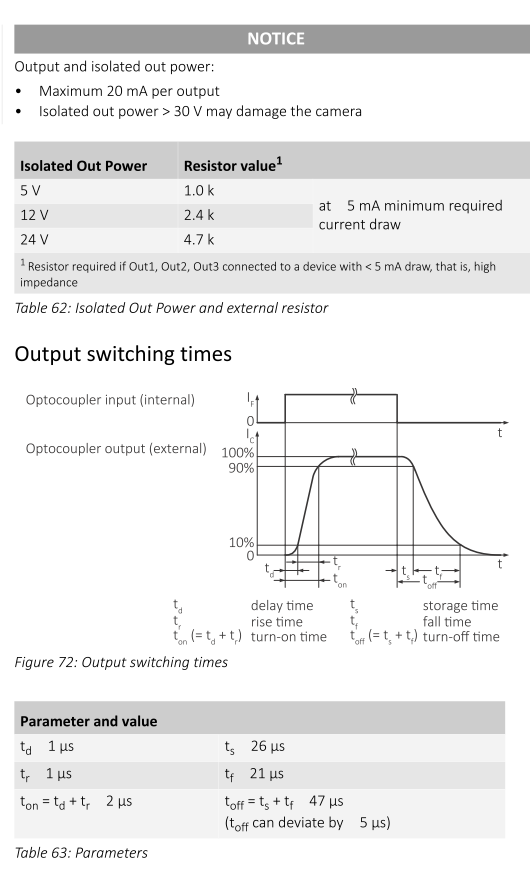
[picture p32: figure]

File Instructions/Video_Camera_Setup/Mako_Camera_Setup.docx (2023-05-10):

Front Camera (Super Fast) Configuration Settings

Configuration settings for both Streampix and MATLAB Image Acquisition

- We are switching software to Norpix/StreamPix Lite – MATLAB consistently crashes after ~20 minutes
- In MATLAB and Streampix output is LINE 3 (not Line 0). This is Line Selector in the Streampix config system seen itemized below.

Streampix Vimba Settings

- ROI
  - Width: 600
  - Height: 800
  - *uncheck Broadcast and Center ROI
- Adjustments – depends on the lighting, but these settings should give you ~360 FPS
  - Exposure: ~.1
  - Gain: ~7.5
  - Frame Rate: ~360
  - Gamma: ~.9
- Settings
  - Image Format: Mono 8
  - Trigger Mode: Off
  - Trigger Source: Line 3 (‘Software’ in MATLAB)
  - Trigger Activation: Rising Edge
  - Acquisition Frame Rate Mode: Basic (‘Off’ in MATLAB)
  - Trigger Selector: Frame Start
  - Line Inverter: False
  - Line Selector: Line 3
  - Line Source: Exposure Active
  - Meta Data Mode: Off
  - DSP Subregion: Off

MATLAB Image Acquisition Settings

- Gain = 10
- Gamma = 1
- Exposure: this may depend – 2.5ms
- Continuous
- Output on Active Frame or Active Exposure.

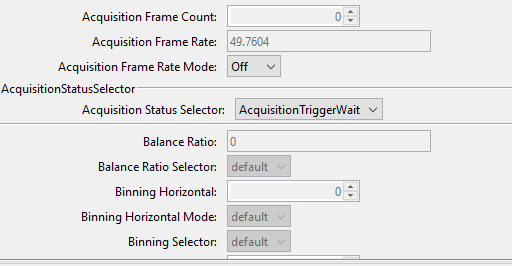
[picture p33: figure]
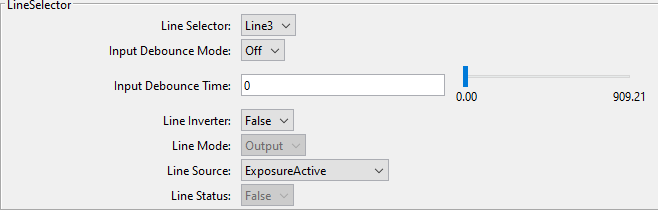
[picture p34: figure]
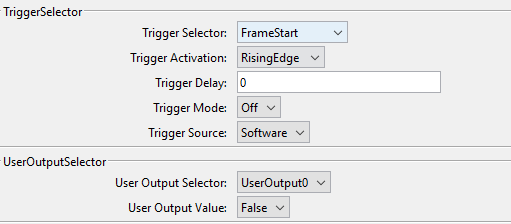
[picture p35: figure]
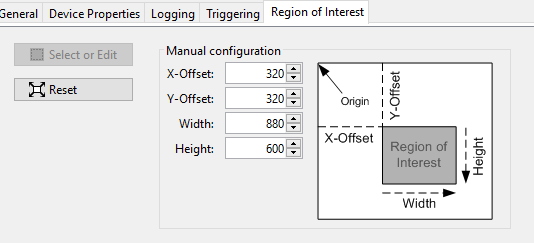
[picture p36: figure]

# Connecting the camera to the neural recording system


The Matlab Image Acquisition Toolbox Graphical User Interface (GUI) and a second circuit were used to configure the camera to send a TTL pulse to the Intan data acquisition system (Intan Technologies, Los Angeles, California, United States) every time a frame was exposed. This allowed the timing of each frame to be aligned with the recorded neural activity. This circuit consisted of an open collector trigger from the camera and a pull up resistor to process the signal for triggering the Intan system. After collection, video information was processed by DeepLabCut (Mathis et al., 2018) and custom Matlab code (github.com/GiaJordan/Behavior_Quantification).

NOTE: Open collector means no voltage goes out – do you need a pullUP resistor? According to https://en.wikipedia.org/wiki/Open_collector this is true ( I was mistakenly using a pulldown resistor)

Looks like the pullup can be in the range of 3KOhm to 6KOhm.

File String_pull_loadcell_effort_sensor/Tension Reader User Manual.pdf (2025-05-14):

# Tension Reading Device User Manual

## CONTENTS

## 1. Introduction

The Tension Reading Device is a precision instrument designed to measure the force exerted on a string that is mounted on a pulley system, specifically for applications involving small animals, such as rats, in research settings. The system integrates a load cell with an HX711 amplifier, a Raspberry Pi Pico microcontroller, and a custom 3D-printed holder to ensure accurate and reliable tension measurements. Data is displayed and recorded in real-time via a graphical user interface (GUI) on a connected computer, with optional storage on a microSD card. This manual provides detailed instructions for setup, operation, calibration, and maintenance of the device.

## 2. Safety Precautions

- Electrical Safety: Ensure the device is powered off and unplugged before making any connections or adjustments to prevent electrical shock or damage.
- Load Cell Handling: Do not apply excessive force (>100 g) to the load cell, as this may damage the sensor.
- Animal Safety: Ensure the string and attachment mechanism are secure and safe for the rat to prevent injury. Monitor the animal during testing.
- Environmental Conditions: Operate the device in a dry, stable environment (0–40°C, non-condensing humidity) to avoid damage to electronic components.
- Proper Setup: Secure the device firmly to prevent movement during operation, which could skew measurements or harm the test subject.

## 3. System Overview

The Tension Reading Device measures the force exerted on a string by a rat using the following components:
- Load Cell with HX711 Amplifier: The load cell converts mechanical force into an electrical signal, amplified by the HX711 for high-precision measurements.
- Raspberry Pi Pico: A microcontroller that collects data from the load cell and communicates with the computer via USB.
- Custom 3D-Printed Holder: A specially designed part that securely mounts the load cell to a 20x20 T-slotted bar, ensuring proper alignment and stability during measurements.
- Graphical User Interface (GUI): A Python-based interface for real-time data visualization, unit selection (grams or newtons), taring, and data recording.
- Optional microSD Card Module: Allows data to be saved directly to a microSD card for offline analysis.

### How the System Works

- The rat pulls on a string attached to the load cell, which is mounted in the 3D-printed holder.
- The load cell detects the force and generates a proportional electrical signal.
- The HX711 amplifier converts this signal into a digital format with high resolution.
- The Raspberry Pi Pico reads the amplified signal at a 13ms interval and sends it to the computer via USB.
- The GUI displays the force in real-time (updated every 100ms) and allows the user to save data to the computer and/or microSD card.
- The system automatically tares on startup, and manual taring is available via the GUI to reset the baseline to 0.0g.

## 4. Setup

### Mechanical Setup

- Mount the 3D-Printed Holder:
- Place the custom 3D-printed holder at the desired location on a 20x20 T-slotted bar.
- Secure the holder to the bar using two M4 screws. Ensure the holder is firmly attached to prevent movement.
- The 3D-printed holder is designed to position the load cell such that the string attachment point is aligned with the rat’s pulling direction.
- Attach the Load Cell:
- Secure the load cell to the 3D-printed holder using the provided mounting holes and appropriate screws.
- Ensure the load cell’s string attachment point is accessible and unobstructed.
- Connect the String:
- Attach a lightweight, durable string to the load cell’s designated attachment point.
- Ensure the string is securely fastened and aligned with the load cell’s sensing axis to avoid off-axis loading, which could affect accuracy.

### Electrical Setup

- Connect the Load Cell to the HX711 Amplifier: Refer to the wiring diagram in Section 5.
- Connect the HX711 to the Raspberry Pi Pico: Use jumper wires to connect the HX711 to the Pico’s GPIO pins as shown in Section 5.
- Optional microSD Card Module:
- Plug a microSD card (≤32GB, formatted as FAT32) into the SD card module.
- Connect the SD card module to the Pico.
- Power and Computer Connection:
- Connect the Raspberry Pi Pico to the computer via a USB cable. The Pico will power on and enter “stand-by” mode, collecting data but not sending it until the GUI is launched.

### Software Setup

- Download the Tension Reader Folder:
- Download the Tension Reader folder.
- This folder contains the GUI code, dependency libraries, and sample data recorded by the load cell.
- Install Python:
- If Python is not installed, download and install Python 3.x from python.org. See Appendix I for detailed instructions.
- Install Dependencies:
- Install the pyserial and matplotlib libraries using pip. See Appendix II for commands.
- Verify microSD Card (if used):
- Ensure the microSD card is formatted as FAT32 and has sufficient free space. See Appendix IV for formatting instructions.
- Ensure “serialPico” port is setup correctly
- Edit the GUI.py file. Ensure that “serialPico” declaration at the start of the code is referencing the correct serial port (set to COM3 by default). See Appendix VII for figuring out which serial port is used.

## 5. Wiring Connection Diagram

- The following diagram illustrates the connections between the load cell, HX711 amplifier, Raspberry Pi Pico, and optional microSD card module. Ensure all connections are secure and correct to avoid data errors.

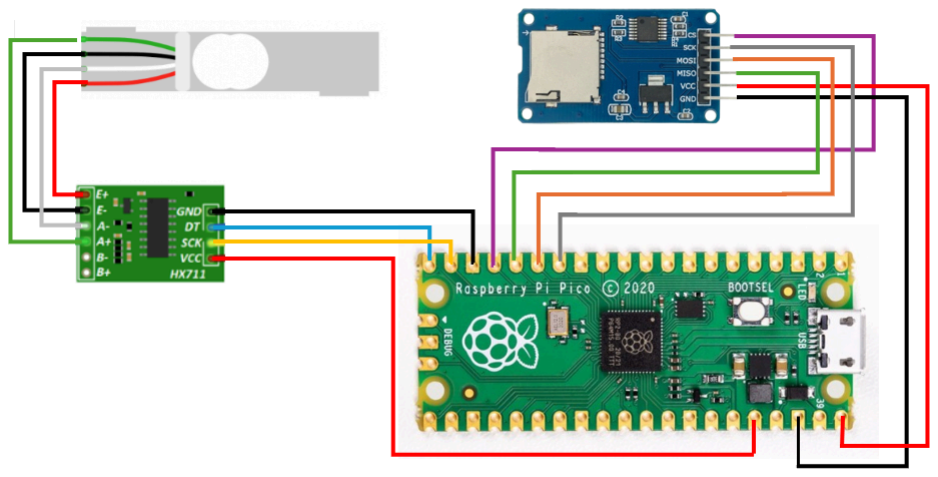
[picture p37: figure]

Notes:
- Use jumper wires or a breadboard for connections.
- Double-check polarity and pin assignments to avoid damaging components.
- The 3D-printed holder does not affect wiring but ensures the load cell remains stable during measurements.

## 6. Operation

- Power On:
- Plug the Raspberry Pi Pico into the computer via USB. The Pico enters “stand-by” mode, collecting data from the load cell but not sending or saving it.
- Launch the GUI:
- Navigate to the Tension Reader folder and run the GUI script (see Appendix V for instructions).
- The GUI will open, and the Pico will begin sending data, plotting force measurements in real-time (updated every 100ms).
- Select Units:
- Use the “Unit” button to toggle between grams (g) and newtons (N).
- Record Data:
- Click the “Record” button to start saving data.
- A new folder will be created in the Tension Reader folder on the computer and on the microSD card (if connected).
- Each time “Record” is turned on within the same session, a new file is created in the same folder.
- Click “Record” again to stop recording.
- Stop the Program:
- Close the GUI by clicking the “X” button in the top-right corner.
- All recorded files are saved, and the Pico returns to “stand-by” mode.
- Disconnect the Raspberry Pi Pico:
- Make sure to always disconnect the Pico after a session to avoid crashes and data corruption
- The Tension Reader is able to run for 2+ hours continuously without issues.

Note: If the GUI fails to open or displays a constant 10.0g reading, refer to the Troubleshooting section.

## 7. Calibration

- Automatic Taring: The Tension Reader automatically tares (sets the baseline to 0.0g) when the Pico is powered on or reset.
- Manual Taring: If a constant load is applied or removed after startup (e.g., the string is adjusted), the baseline may shift. Click the “Tare” button in the GUI to reset the baseline to 0.0g.
- Verification: To ensure accuracy, apply a known weight (e.g., 100g) to the load cell and verify the GUI reading matches the expected value. Contact support if discrepancies persist.

## 8. Specifications

- Measurement Range: 0–100g (adjustable based on load cell specifications).
- Resolution: Data collected at 13ms intervals by the Pico; displayed at 100ms intervals in the GUI.
- Units: Grams (g) or Newtons (N), user-selectable.
- Power Supply: USB-powered via Raspberry Pi Pico (5V).
- Storage: Optional microSD card (≤32GB, FAT32 format).
- Load Cell: High-precision with HX711 amplifier for 24-bit resolution.
- Mounting: Custom 3D-printed holder for 20x20 T-slotted bar, secured with M4 screws.
- Operating Conditions: 0–40°C, non-condensing humidity.
- Git Repository: https://github.com/davidpolk/Load-Cell

## 9. Troubleshooting

- GUI Does Not Open:
- Ensure Python, pyserial, and matplotlib are installed (see Appendices I and II).
- Verify the Tension Reader folder contains the correct GUI script.
- Constant 10.0g Reading:
- Check load cell and HX711 wiring (see Section 5).
- Ensure the load cell is not overloaded or damaged.
- Confirm the Pico is connected to the computer and recognized as a USB device.
- Verify the correct COM port is selected in the GUI code (see Appendix VII).
- Reset the Pico by unplugging and replugging the USB cable.
- Inaccurate Readings:
- Perform a manual tare using the GUI “Tare” button.
- Check for loose connections or off-axis loading on the load cell.
- Verify the 3D-printed holder is securely mounted.
- microSD Card Issues:
- Ensure the card is ≤32GB and formatted as FAT32 (see Appendix IV).
- Check wiring to the SD card module (see Section 5).

For further assistance, refer to the Contact Information section.

## 10. Maintenance

- Cleaning: Wipe the 3D-printed holder and load cell with a dry or slightly damp cloth. Avoid liquids near electronic components.
- Load Cell Care: Inspect the load cell regularly for signs of wear or damage. Replace if accuracy degrades.

- String Replacement: Replace the string if it shows signs of fraying or stretching to ensure consistent measurements.
- Storage: Store the device in a dry, dust-free environment when not in use.
- Firmware Updates: Check with the supplier for firmware updates to the Raspberry Pi Pico to improve performance or fix bugs.
- 3D-Printed Holder: Inspect for cracks or deformation. Contact the supplier for a replacement if needed.

## 11. Contact Information

For technical support, or inquiries: Email: contact@darionengineering.com

## 12. Appendices

## Appendix I: Installing Python

To install the latest version of python, use the link below https://www.python.org/downloads/

## Appendix II: Installing dependencies

Every dependency used by the GUI can be found in /lib inside the GUI folder except for pyserial and matplotlib. These can be installed using pip. To do so, open the terminal on your PC and write the following commands one at a time

- pip install pyserial
- pip install matplotlib

## Appendix III: Recording Data

As long as the Pico is powered on, the Tension Reader will constantly be gathering data from the load cell. However, this data will not be sent to the computer, nor saved into files until a command is sent by the GUI (or manually as seen in Appendix VI).

When a recording is started, a new folder will be created within the GUI folder on the computer, and within the SD card if connected. The folder saved in the SD card and Computer will have the same name and hold the exact same data.

In this context, a new “session” is created every time the GUI is opened. As such, only one folder will be created per session. The name of each session folder will be the date-time of when the session has started (when opening the GUI) in the following format: YYYY-MM-DD_HH-MM-SS

## Appendix IV: SD Card Specifications

The system works best with a microSD card of 32GB or lower. This is because the SD card must be formatted in FAT32 in order for the Pico to interact with it. To format the SD card:

- Plug SD Card into computer
- Open File explorer and find SD card storage device
- Right-click on our SD Card device then click on Format
- Choose "FAT32" from the File System dropdown

## Appendix V: Using GUI

There are 3 ways of running the GUI:

- Double click on file
- To achieve this, you must first right-click on GUI.py
- Select Open with… > Python 3.12 (or current python version)
- Once done this, the user should be able to run the GUI in the future by simply double-clicking on the file
- Run through Terminal
- Open the terminal on your PC
- Navigate to the directory where GUI.py is located
- Type “python GUI.py” in the terminal
- Run through Visual Studios or IDE.
- If you have Visual Studios, VSCode or any other IDE, you can load the code, edit it if needed, and run it through there

- Keep in mind, these IDE’s may require Python extensions if not yet installed

## Appendix VI: Using Tension Reader without GUI

It is possible to gather and record data without using the GUI. To do so, the user must use an IDE such as Thonny. This is mainly because the user must be able to send commands such as Acquire or Record to the Pico for it to carry out these actions. To do so, the user must:

1. Install Thonny
2. Open Thonny
3. Connect Pico to computer
4. Open communication between Thonny and Pico
a. Usually, this can be done by simply clicking on the “STOP” button on Thonny’s top toolbar.
b. If that does not work, Click on the bottom right corner of the Thonny window. Normally, it says something like “Local Python 3 - Thonny’s Python” . Then select the serial port corresponding to the Pico (e.g. COM3 Raspberry Pi)
5. Once Thonny has established communication with the Pico, a panel should open on the bottom left corner of Thonny, under the local computer files panel. This panel shows all files stored inside the Pico.
6. Double Click on the “main.py” file to open it on Thonny
7. Click “Run Current Script” (green play button on Thonny’s top toolbar.)
8. The Pico will start running the program in “Stand-by” mode.
9. To show the printed measurements on the console, type the character a (acquire) into Thonny’s console, followed by an Enter
10.To start recording (saving data into SD card), type the character r (record) into Thonny’s console, followed by an Enter
11. The user can use the “Tare” and “Unit” functions by typing t and u respectively into Thonny’s console, followed by an Enter

## Appendix VII: Checking Raspberry Pi Pico communication port

In order for the GUI to establish communication with the Pico, it must look at the correct port. By default, the GUI looks at the COM3 port. However, the USB port on your computer might be different. There are two ways of seeing what port the Pico is connected to:

1. Using Device Manager:
a. Open the Device manager on your computer
b. Scroll down to find and open the “Ports (COM & LPT)” dropdown
c. Take note of the COM# connections found in this dropdown
d. Connect the Pico to the computer
e. At this point, the list will update. A new COM device should appear in the Ports dropdown called “COM#”. This refers to the USB port on which the Pico is connected to.
2. Using Thonny:
a. Open Thonny
b. Connect Pico to computer
c. Open communication between Thonny and Pico
i. Usually, this can be done by simply clicking on the “STOP” button on Thonny’s top toolbar.
ii. | If that does not work, Click on the bottom right corner of the Thonny
| window. Normally, it says something like “Local Python 3 - Thonny’s
| Python” . Then select the serial port corresponding to the Pico (e.g.
| COM3 Raspberry Pi)
iii. | This “COM#” name that appears next to “Raspberry Pi” in this list
| refers to the USB port on which the Pico is connected to.

Once you have the name of your COM port, open the GUI.py file and change the following line:

serialPico = serial.Serial("COM3", 115200)

so that “COM3” now reflects the USB port on which the Pico is connected to.

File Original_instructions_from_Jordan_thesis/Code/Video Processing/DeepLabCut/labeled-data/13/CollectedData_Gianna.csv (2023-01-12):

scorer | Gianna | Gianna | Gianna | Gianna | Gianna | Gianna
bodyparts | Nose | Nose | Left Paw | Left Paw | Right Paw | Right Paw
coords | x | y | x | y | x | y
labeled-data\13\img015989.png | 333.3997003218767 | 306.32304191794003 | 281.3075030522773 | 749.1067187095343 | 244.84296496355773 | 534.2264049724371
labeled-data\13\img045682.png | 263.0752340079175 | 411.8097413888786 | 274.79597839357734 | 553.7609789485368 | 272.1913685300974 | 639.7131044433756
labeled-data\13\img054818.png | 386.794202523216 | 249.02162492138075 | 360.7481038884164 | 403.9959117984388 | 324.2835657996968 | 670.9684228051352
labeled-data\13\img054852.png | 382.88728772799595 | 259.4400643753006 | 359.4457989566763 | 406.6005216619187 | 328.1904805949166 | 668.3638129416554
labeled-data\13\img054932.png | 342.5158348440566 | 213.85939176440115 | 325.58587073143667 | 473.0180731806579 | 291.72594250619704 | 616.271615672056
labeled-data\13\img054949.png | 346.4227496392764 | 217.76630655962117 | 324.2835657996968 | 500.36647674719745 | 265.67984387139745 | 512.0872211328574
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

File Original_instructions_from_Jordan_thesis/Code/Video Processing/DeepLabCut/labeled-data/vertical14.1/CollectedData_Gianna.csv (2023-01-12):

scorer | Gianna | Gianna | Gianna | Gianna | Gianna | Gianna
bodyparts | Nose | Nose | Left Paw | Left Paw | Right Paw | Right Paw
coords | x | y | x | y | x | y
labeled-data\vertical14.1\img058471.png | 210.06264964086188 | 499.54788507581804 | 256.0323224261772 | 693.6420590582602 | 181.97007182761365 | 448.4704708699122
labeled-data\vertical14.1\img058567.png | 196.01636073423776 | 485.50159616919393 | 219.00119712689536 | 627.2414205905827 | 167.92378292098954 | 559.5638467677575
labeled-data\vertical14.1\img058635.png | 230.49361532322416 | 338.6540303272146 | 217.7242617717477 | 560.840782122905 | 179.41620111731834 | 470.17837190742216
labeled-data\vertical14.1\img058642.png | 231.77055067837182 | 329.71548284118114 | 225.38587390263365 | 567.2254588986433 | 193.46249002394245 | 406.3316041500399
labeled-data\vertical14.1\img058666.png | 270.0786113328013 | 297.79209896248994 | 241.98603351955308 | 595.3180367118915 | 244.53990422984828 | 410.16241021548285
labeled-data\vertical14.1\img075015.png | 262.41699920191536 | 434.4241819632881 | 261.1400638467678 | 636.1799680766162 | 229.21667996807662 | 761.3196328810855
labeled-data\vertical14.1\img075033.png | 258.5861931364725 | 402.5007980845969 | 252.20151636073422 | 646.3954509177973 | 216.44732641660016 | 620.8567438148444
labeled-data\vertical14.1\img075039.png | 253.47845171588187 | 394.8391859537111 | 243.26296887470062 | 654.0570630486832 | 202.40103750997605 | 565.9485235434956
labeled-data\vertical14.1\img075063.png | 272.6324820430966 | 366.74660814046285 | 245.81683958499593 | 664.2725458898644 | 252.20151636073422 | 440.8088587390264
labeled-data\vertical14.1\img075079.png | 293.0634477254589 | 345.0387071029529 | 275.18635275339193 | 684.7035115722267 | 276.4632881085395 | 472.7322426177175
labeled-data\vertical14.1\img075102.png | 317.32521947326404 | 329.71548284118114 | 321.1560255387071 | 683.4265762170792 | 305.83280127693524 | 511.0403032721469
labeled-data\vertical14.1\img075112.png | 318.6021548284118 | 325.88467677573817 | 341.5869912210694 | 586.3794892258579 | 314.7713487629687 | 545.5175578611334
labeled-data\vertical14.1\img075117.png | 309.6636073423783 | 325.88467677573817 | 350.5255387071029 | 544.2406225059857 | 321.1560255387071 | 565.9485235434956
labeled-data\vertical14.1\img075127.png | 314.7713487629687 | 324.6077414205905 | 353.0794094173982 | 474.00917797286513 | 327.5407023144453 | 596.5949720670392
labeled-data\vertical14.1\img075139.png | 316.0482841181165 | 327.1616121308858 | 328.81763766959284 | 426.7625698324023 | 326.26376695929775 | 622.1336791699921
labeled-data\vertical14.1\img075149.png | 307.109736632083 | 324.6077414205905 | 316.0482841181165 | 461.2398244213887 | 317.32521947326404 | 640.0107741420591
labeled-data\vertical14.1\img075177.png | 271.35554668794884 | 319.5 | 284.1249002394254 | 518.7019154030327 | 281.5710295291301 | 694.918994413408
labeled-data\vertical14.1\img075185.png | 267.524740622506 | 318.22306464485234 | 268.80167597765353 | 542.963687150838 | 248.37071029529125 | 666.8264166001597
labeled-data\vertical14.1\img075191.png | 268.80167597765353 | 322.0538707102952 | 261.1400638467678 | 560.840782122905 | 225.38587390263365 | 602.9796488427774
labeled-data\vertical14.1\img075200.png | 266.2478052673582 | 338.6540303272146 | 256.0323224261772 | 586.3794892258579 | 222.83200319233833 | 545.5175578611334
labeled-data\vertical14.1\img075208.png | 267.524740622506 | 361.63886671987234 | 256.0323224261772 | 596.5949720670392 | 230.49361532322416 | 546.7944932162809
labeled-data\vertical14.1\img075224.png | 264.9708699122107 | 392.28531524341577 | 257.30925778132473 | 646.3954509177973 | 224.108938547486 | 523.8096568236233
labeled-data\vertical14.1\img075236.png | 266.2478052673582 | 399.9469273743017 | 257.30925778132473 | 683.4265762170792 | 247.0937749401436 | 490.60933758978456
labeled-data\vertical14.1\img075257.png | 291.78651237031113 | 371.8543495610535 | 282.84796488427764 | 726.842378292099 | 276.4632881085395 | 536.5790103750999
labeled-data\vertical14.1\img075272.png | 299.44812450119707 | 352.70031923383874 | 310.94054269752587 | 712.7960893854749 | 291.78651237031113 | 578.7178770949721
labeled-data\vertical14.1\img075281.png | 295.6173184357542 | 343.76177174780526 | 337.75618515562655 | 617.0259377494015 | 296.89425379090176 | 614.4720670391062
labeled-data\vertical14.1\img075286.png | 298.1711891460495 | 342.4848363926576 | 339.0331205107741 | 563.3946528332003 | 305.83280127693524 | 629.795291300878
labeled-data\vertical14.1\img075292.png | 296.89425379090176 | 339.9309656823623 | 336.4792498004788 | 508.4864325618516 | 308.38667198723056 | 647.672386272945
labeled-data\vertical14.1\img075298.png | 294.34038308060644 | 336.1001596169193 | 328.81763766959284 | 471.4553072625698 | 304.5558659217877 | 652.7801276935356
labeled-data\vertical14.1\img075306.png | 285.40183559457296 | 327.1616121308858 | 299.44812450119707 | 445.9166001596169 | 304.5558659217877 | 655.333998403831
labeled-data\vertical14.1\img086564.png | 164.09297685554668 | 401.22386272944937 | 286.67877094972073 | 528.9173982442139 | 199.84716679968074 | 571.0562649640863
labeled-data\vertical14.1\img086585.png | 106.63088587390257 | 567.2254588986433 | 294.34038308060644 | 555.7330407023145 | 188.35474860335194 | 665.549481245012

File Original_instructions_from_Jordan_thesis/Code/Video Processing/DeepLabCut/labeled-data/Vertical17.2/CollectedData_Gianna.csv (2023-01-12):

scorer | Gianna | Gianna | Gianna | Gianna | Gianna | Gianna
bodyparts | Nose | Nose | Left Paw | Left Paw | Right Paw | Right Paw
coords | x | y | x | y | x | y
labeled-data\Vertical17.2\img031366.png | 294.34038308060644 | 430.59337589784514 | 340.31005586592187 | 579.9948124501198 | 302.0019952114924 | 579.9948124501198
labeled-data\Vertical17.2\img031407.png | 335.20231444533124 | 458.68595371109336 | 393.9413407821228 | 582.5486831604151 | 290.5095770151636 | 641.2877094972068
labeled-data\Vertical17.2\img031414.png | 337.75618515562655 | 457.4090183559457 | 392.66440542697524 | 530.1943335993616 | 296.89425379090176 | 615.7490023942539
labeled-data\Vertical17.2\img031433.png | 330.0945730247406 | 453.57821229050285 | 365.8487629688748 | 466.3475658419793 | 340.31005586592187 | 560.840782122905
labeled-data\Vertical17.2\img121014.png | 245.81683958499593 | 452.3012769353552 | 234.32442138866713 | 693.6420590582602 | 192.1855546687948 | 614.4720670391062
labeled-data\Vertical17.2\img121028.png | 250.92458100558656 | 426.7625698324023 | 229.21667996807662 | 702.5806065442938 | 201.1241021548284 | 523.8096568236233
labeled-data\Vertical17.2\img121042.png | 256.0323224261772 | 398.66999201915405 | 236.87829209896245 | 703.8575418994415 | 233.04748603351948 | 525.0865921787711
labeled-data\Vertical17.2\img121060.png | 253.47845171588187 | 374.4082202713488 | 258.5861931364725 | 706.4114126097368 | 241.98603351955308 | 528.9173982442139
labeled-data\Vertical17.2\img121077.png | 254.75538707102942 | 348.86951316839577 | 289.2326416600158 | 659.1648044692738 | 241.98603351955308 | 550.625299281724
labeled-data\Vertical17.2\img121083.png | 262.41699920191536 | 342.4848363926576 | 295.6173184357542 | 596.5949720670392 | 252.20151636073422 | 567.2254588986433
labeled-data\Vertical17.2\img121089.png | 263.6939345570629 | 345.0387071029529 | 304.5558659217877 | 542.963687150838 | 256.0323224261772 | 573.6101356743816
labeled-data\Vertical17.2\img121095.png | 263.6939345570629 | 345.0387071029529 | 305.83280127693524 | 493.1632083000799 | 256.0323224261772 | 582.5486831604151
labeled-data\Vertical17.2\img121140.png | 243.26296887470062 | 276.08419792498 | 226.6628092577813 | 499.54788507581804 | 190.90861931364714 | 502.10175578611336
labeled-data\Vertical17.2\img121146.png | 239.43216280925776 | 274.80726256983235 | 221.55506783719068 | 508.4864325618516 | 183.2470071827613 | 449.7474062250599
labeled-data\Vertical17.2\img121154.png | 240.70909816440542 | 267.1456504389465 | 224.108938547486 | 518.7019154030327 | 179.41620111731834 | 398.66999201915405
labeled-data\Vertical17.2\img121164.png | 243.26296887470062 | 256.93016759776526 | 224.108938547486 | 530.1943335993616 | 206.2318435754189 | 382.0698324022346
labeled-data\Vertical17.2\img121239.png | 282.84796488427764 | 241.6069433359936 | 295.6173184357542 | 597.8719074221868 | 258.5861931364725 | 513.5941739824422
labeled-data\Vertical17.2\img121246.png | 275.18635275339193 | 240.33000798084595 | 303.27893056663993 | 521.255786113328 | 270.0786113328013 | 532.7482043096568
labeled-data\Vertical17.2\img121252.png | 280.29409417398233 | 240.33000798084595 | 302.0019952114924 | 456.13208300079805 | 275.18635275339193 | 551.9022346368715
labeled-data\Vertical17.2\img121258.png | 287.9557063048683 | 239.0530726256983 | 316.0482841181165 | 415.27015163607336 | 290.5095770151636 | 568.502394253791
labeled-data\Vertical17.2\img121267.png | 289.2326416600158 | 239.0530726256983 | 327.5407023144453 | 364.19273743016754 | 289.2326416600158 | 592.7641660015962
labeled-data\Vertical17.2\img121275.png | 291.78651237031113 | 232.66839584996 | 309.6636073423783 | 327.1616121308858 | 293.0634477254589 | 610.6412609736633
labeled-data\Vertical17.2\img121288.png | 271.35554668794884 | 218.6221069433359 | 286.67877094972073 | 360.3619313647247 | 279.0171588188348 | 619.5798084596968
labeled-data\Vertical17.2\img121294.png | 267.524740622506 | 213.51436552274538 | 280.29409417398233 | 361.63886671987234 | 250.92458100558656 | 596.5949720670392
labeled-data\Vertical17.2\img121297.png | 266.2478052673582 | 210.96049481245007 | 271.35554668794884 | 379.5159616919393 | 233.04748603351948 | 550.625299281724
labeled-data\Vertical17.2\img121299.png | 262.41699920191536 | 205.85275339185944 | 273.90941739824416 | 389.73144453312045 | 230.49361532322416 | 513.5941739824422
labeled-data\Vertical17.2\img121300.png | 266.2478052673582 | 208.40662410215475 | 271.35554668794884 | 382.0698324022346 | 227.93974461292896 | 503.378691141261
labeled-data\Vertical17.2\img121303.png | 263.6939345570629 | 205.85275339185944 | 267.524740622506 | 398.66999201915405 | 225.38587390263365 | 465.07063048683165
labeled-data\Vertical17.2\img121307.png | 270.0786113328013 | 205.85275339185944 | 257.30925778132473 | 416.547086991221 | 210.06264964086188 | 426.7625698324023
labeled-data\Vertical17.2\img121313.png | 264.9708699122107 | 203.29888268156412 | 247.0937749401436 | 440.8088587390264 | 203.6779728651236 | 359.084996009577
labeled-data\Vertical17.2\img121321.png | 259.86312849162005 | 200.74501197126892 | 238.1552274541101 | 465.07063048683165 | 215.1703910614525 | 292.68435754189943
labeled-data\Vertical17.2\img121334.png | 279.0171588188348 | 196.91420590582595 | 238.1552274541101 | 507.20949720670393 | 250.92458100558656 | 315.66919393455703
labeled-data\Vertical17.2\img126326.png |  |  | 331.37150837988816 | 413.9932162809258 | 321.1560255387071 | 314.3922585794094
labeled-data\Vertical17.2\img126338.png | 296.89425379090176 | 102.42098962490013 | 346.69473264166004 | 286.29968076616115 | 326.26376695929775 | 346.31564245810057
labeled-data\Vertical17.2\img126348.png | 303.27893056663993 | 117.7442138866719 | 340.31005586592187 | 204.57581803671178 | 322.43296089385467 | 374.4082202713488
labeled-data\Vertical17.2\img126386.png | 264.9708699122107 | 119.02114924181956 | 298.1711891460495 | 297.79209896248994 | 298.1711891460495 | 472.7322426177175
labeled-data\Vertical17.2\img126412.png | 250.92458100558656 | 96.03631284916185 | 266.2478052673582 | 346.31564245810057 | 259.86312849162005 | 528.9173982442139
labeled-data\Vertical17.2\img126432.png | 241.98603351955308 | 83.26695929768539 | 224.108938547486 | 389.73144453312045 | 173.03152434158017 | 295.23822825219463
labeled-data\Vertical17.2\img126439.png | 236.87829209896245 | 81.99002394253773 | 224.108938547486 | 399.9469273743017 | 185.80087789305662 | 202.02194732641647
labeled-data\Vertical17.2\img126447.png | 244.53990422984828 | 88.37470071827602 | 224.108938547486 | 416.547086991221 | 229.21667996807662 | 153.49840383080596
labeled-data\Vertical17.2\img126549.png | 197.29329608938542 | 101.14405426975247 | 333.92537909018347 | 440.8088587390264 | 312.21747805267364 | 313.1153232242617

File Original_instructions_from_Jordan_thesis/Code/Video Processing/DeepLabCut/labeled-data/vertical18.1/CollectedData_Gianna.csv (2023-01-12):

scorer | Gianna | Gianna | Gianna | Gianna | Gianna | Gianna
bodyparts | Nose | Nose | Left Paw | Left Paw | Right Paw | Right Paw
coords | x | y | x | y | x | y
labeled-data\vertical18.1\img089527.png | 224.108938547486 | 442.08579409417393 | 233.04748603351948 | 774.088986432562 | 206.2318435754189 | 720.4577015163609
labeled-data\vertical18.1\img091280.png | 275.18635275339193 | 209.6835594573024 | 252.20151636073422 | 458.68595371109336 | 235.6013567438148 | 375.68515562649634
labeled-data\vertical18.1\img091396.png | 220.27813248204302 | 299.0690343176376 | 279.0171588188348 | 462.51675977653633 | 206.2318435754189 | 485.50159616919393
labeled-data\vertical18.1\img091419.png | 167.92378292098954 | 439.53192338387873 | 287.9557063048683 | 461.2398244213887 | 194.7394253790901 | 568.502394253791
labeled-data\vertical18.1\img094014.png | 293.0634477254589 | 217.34517158818824 | 280.29409417398233 | 618.3028731045492 | 290.5095770151636 | 421.65482841181165
labeled-data\vertical18.1\img094023.png | 298.1711891460495 | 226.28371907422184 | 317.32521947326404 | 514.8711093375898 | 299.44812450119707 | 442.08579409417393
labeled-data\vertical18.1\img094046.png | 300.72505985634484 | 232.66839584996 | 327.5407023144453 | 306.73064644852354 | 316.0482841181165 | 513.5941739824422
labeled-data\vertical18.1\img094068.png | 270.0786113328013 | 231.39146049481235 | 290.5095770151636 | 371.8543495610535 | 287.9557063048683 | 574.8870710295291
labeled-data\vertical18.1\img094082.png | 258.5861931364725 | 223.72984836392652 | 276.4632881085395 | 439.53192338387873 | 222.83200319233833 | 516.1480446927375
labeled-data\vertical18.1\img094086.png | 252.20151636073422 | 222.45291300877886 | 264.9708699122107 | 453.57821229050285 | 212.6165203511572 | 459.962889066241
labeled-data\vertical18.1\img094092.png | 256.0323224261772 | 225.00678371907418 | 240.70909816440542 | 486.7785315243416 | 210.06264964086188 | 380.79289704708697
labeled-data\vertical18.1\img094100.png | 252.20151636073422 | 231.39146049481235 | 229.21667996807662 | 544.2406225059857 | 216.44732641660016 | 318.22306464485234
labeled-data\vertical18.1\img094111.png | 262.41699920191536 | 240.33000798084595 | 233.04748603351948 | 585.1025538707104 | 239.43216280925776 | 360.3619313647247
labeled-data\vertical18.1\img094136.png | 279.0171588188348 | 232.66839584996 | 272.6324820430966 | 648.9493216280927 | 282.84796488427764 | 451.02434158020753
labeled-data\vertical18.1\img094147.png | 281.5710295291301 | 233.94533120510766 | 308.38667198723056 | 544.2406225059857 | 285.40183559457296 | 504.6556264964087
labeled-data\vertical18.1\img094153.png | 284.1249002394254 | 231.39146049481235 | 319.87909018355936 | 466.3475658419793 | 293.0634477254589 | 540.4098164405427
labeled-data\vertical18.1\img094160.png | 285.40183559457296 | 233.94533120510766 | 327.5407023144453 | 380.79289704708697 | 290.5095770151636 | 574.8870710295291
labeled-data\vertical18.1\img094171.png | 270.0786113328013 | 231.39146049481235 | 276.4632881085395 | 348.86951316839577 | 281.5710295291301 | 610.6412609736633
labeled-data\vertical18.1\img094190.png | 239.43216280925776 | 227.5606544293695 | 253.47845171588187 | 396.11612130885874 | 238.1552274541101 | 633.6260973663209
labeled-data\vertical18.1\img094199.png | 231.77055067837182 | 217.34517158818824 | 244.53990422984828 | 416.547086991221 | 210.06264964086188 | 620.8567438148444
labeled-data\vertical18.1\img094206.png | 230.49361532322416 | 210.96049481245007 | 235.6013567438148 | 452.3012769353552 | 187.07781324820428 | 526.3635275339186
labeled-data\vertical18.1\img094209.png | 227.93974461292896 | 213.51436552274538 | 226.6628092577813 | 472.7322426177175 | 178.13926576217068 | 485.50159616919393
labeled-data\vertical18.1\img094213.png | 227.93974461292896 | 212.23743016759772 | 215.1703910614525 | 495.71707901037513 | 175.58539505187548 | 433.14724660814045
labeled-data\vertical18.1\img133773.png | 257.30925778132473 | 176.48324022346355 | 259.86312849162005 | 435.70111731843576 | 215.1703910614525 | 327.1616121308858
labeled-data\vertical18.1\img133796.png | 281.5710295291301 | 186.6987230646448 | 247.0937749401436 | 528.9173982442139 | 280.29409417398233 | 323.33080606544286
labeled-data\vertical18.1\img133810.png | 295.6173184357542 | 190.52952913008767 | 280.29409417398233 | 567.2254588986433 | 302.0019952114924 | 364.19273743016754
labeled-data\vertical18.1\img133819.png | 304.5558659217877 | 180.31404628890652 | 307.109736632083 | 504.6556264964087 | 316.0482841181165 | 401.22386272944937
labeled-data\vertical18.1\img133834.png | 319.87909018355936 | 181.59098164405418 | 353.0794094173982 | 296.5151636073423 | 340.31005586592187 | 434.4241819632881
labeled-data\vertical18.1\img133887.png | 266.2478052673582 | 172.6524341580207 | 280.29409417398233 | 365.4696727853152 | 259.86312849162005 | 527.6404628890663
labeled-data\vertical18.1\img133894.png | 266.2478052673582 | 175.2063048683159 | 271.35554668794884 | 394.8391859537111 | 217.7242617717477 | 431.8703112529928
labeled-data\vertical18.1\img133900.png | 264.9708699122107 | 180.31404628890652 | 266.2478052673582 | 424.20869912210696 | 215.1703910614525 | 353.9772545889864
labeled-data\vertical18.1\img133905.png | 266.2478052673582 | 185.42178770949715 | 254.75538707102942 | 440.8088587390264 | 224.108938547486 | 297.79209896248994
labeled-data\vertical18.1\img133910.png | 264.9708699122107 | 190.52952913008767 | 256.0323224261772 | 461.2398244213887 | 226.6628092577813 | 260.76097366320823
labeled-data\vertical18.1\img133954.png | 307.109736632083 | 184.1448523543495 | 309.6636073423783 | 459.962889066241 | 316.0482841181165 | 383.3467677573823
labeled-data\vertical18.1\img133965.png | 316.0482841181165 | 187.97565841979247 | 349.24860335195535 | 315.66919393455703 | 328.81763766959284 | 411.4393455706305

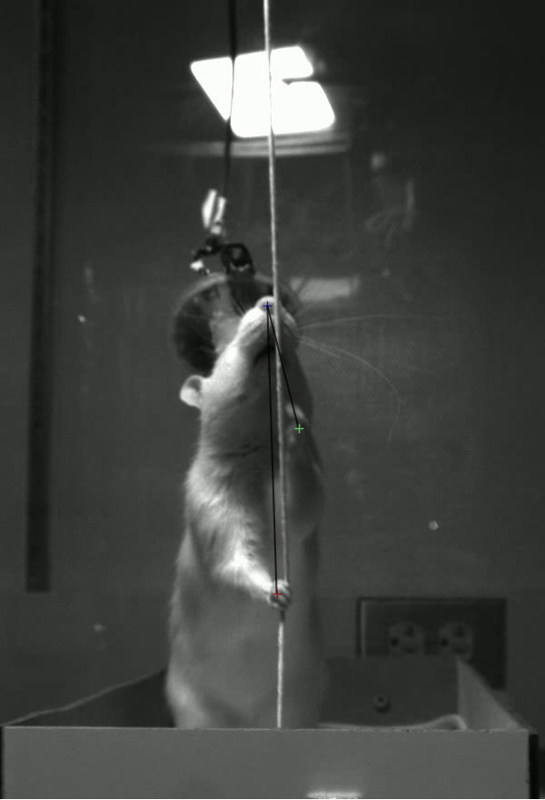
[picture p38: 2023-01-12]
Original_instructions_from_Jordan_thesis/Code/Video Processing/DeepLabCut/labeled-data/vertical14.1_labeled/img075298_bodypart.png

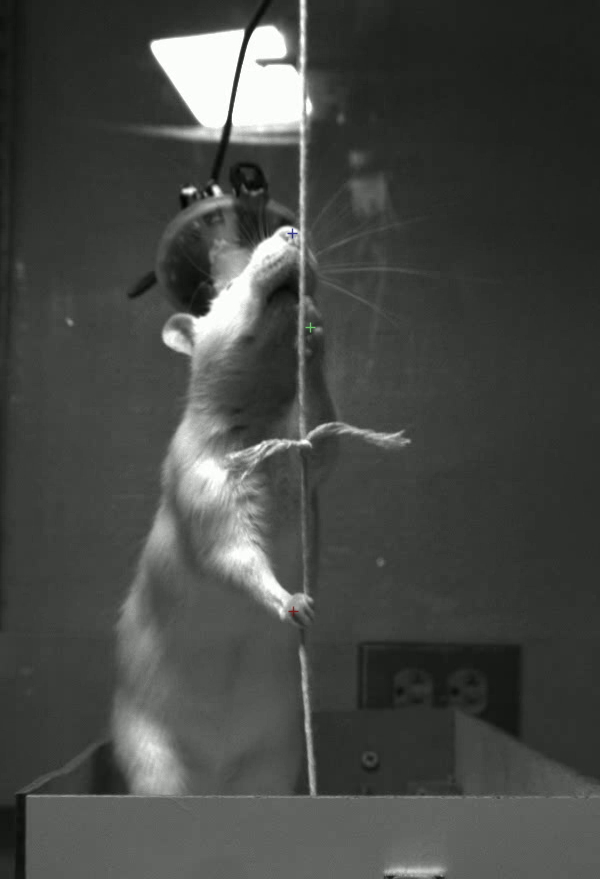
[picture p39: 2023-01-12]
Original_instructions_from_Jordan_thesis/Code/Video Processing/DeepLabCut/labeled-data/Vertical17.2_labeled/img121275.png

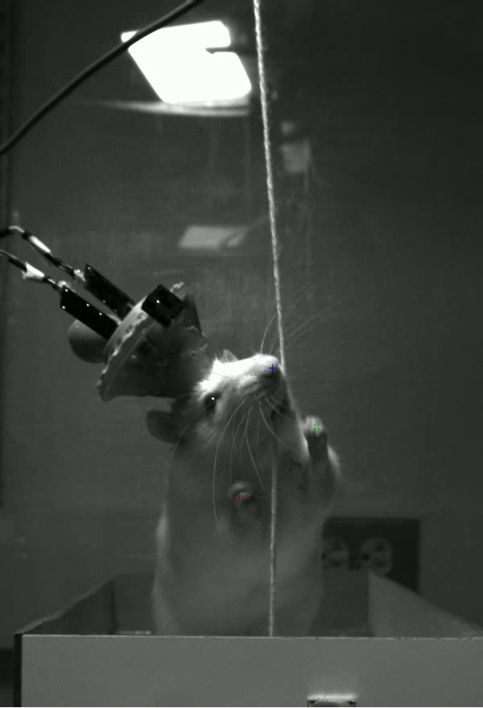
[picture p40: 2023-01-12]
Original_instructions_from_Jordan_thesis/Code/Video Processing/DeepLabCut/labeled-data/Vertical17.2_labeled/img031414.png

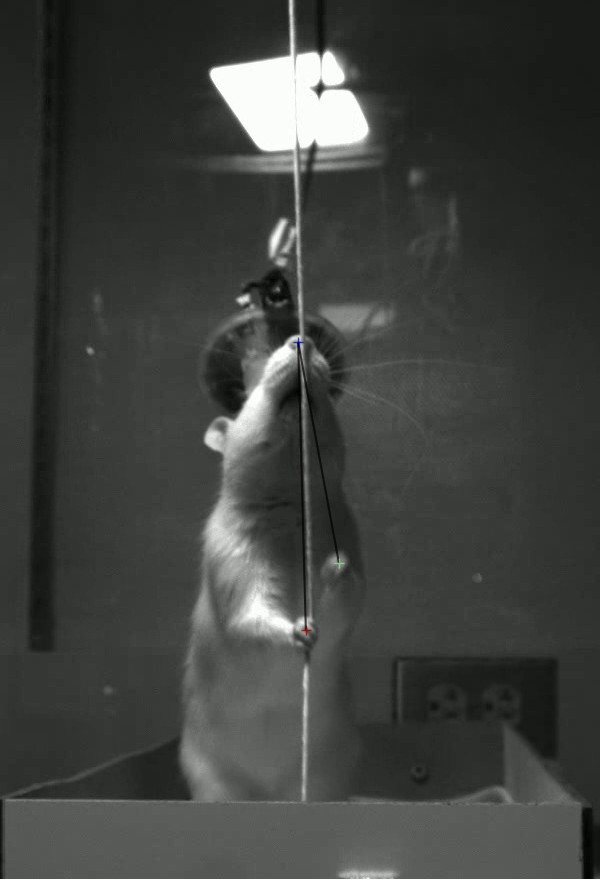
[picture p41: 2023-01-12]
Original_instructions_from_Jordan_thesis/Code/Video Processing/DeepLabCut/labeled-data/vertical14.1_labeled/img075286_bodypart.png

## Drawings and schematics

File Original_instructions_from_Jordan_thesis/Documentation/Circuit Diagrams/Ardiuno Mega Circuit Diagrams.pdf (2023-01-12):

# Feeder CONNECTOR ECODER

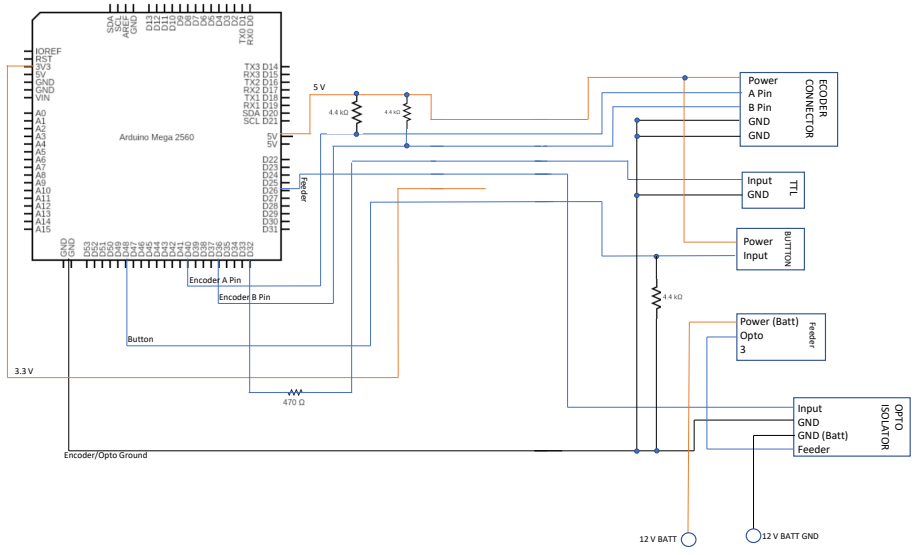
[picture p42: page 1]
Encoder A Pin; Encoder B Pin; Feeder; Button; Power Input; ISOLATOR; OPTO; BUTTTON; Input GND GND (Batt); Power A Pin B Pin GND GND; TTL; Input GND; Power (Batt) Opto 3; 12 V BATT; 12 V BATT GND

Encoder/Opto Ground

# Feeder CONNECTOR ECODER

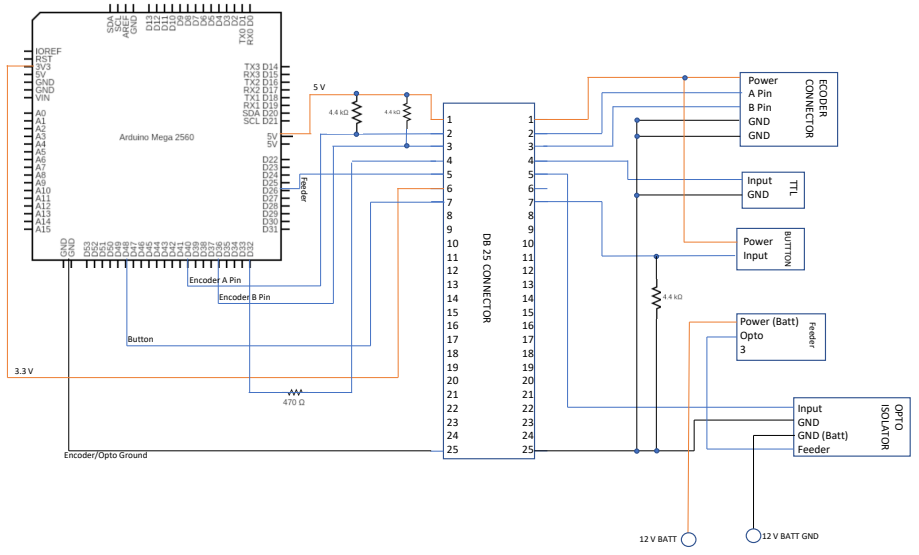
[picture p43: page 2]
Encoder A Pin; Encoder B Pin; Feeder; Button; Power Input; DB 25 CONNECTOR; ISOLATOR; OPTO; BUTTTON; Input GND GND (Batt); Power A Pin B Pin GND GND; TTL; Input GND; Power (Batt) Opto 3; 12 V BATT; 12 V BATT GND

25 Encoder/Opto Ground

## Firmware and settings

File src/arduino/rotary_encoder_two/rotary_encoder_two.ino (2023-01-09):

///////////////////////////////////////////////////////
// Code to sense two rotary encoders simultaneously and send signals 
// out the serial and digital outputs.
//
// Three DIGITAL IO OUTPUTs for each encoder (so 6 total + ground): 
//
// direction (high=cw), tic, full rotation
//
// The serial out is formatted for a csv file that has the... 
//    Code,time(ms), direction, tic, full rotation.
//
// LPD3806 – Optical Rotary Encoder
// If you use a different encoder, you should just need to adjust the two TICS 
// constants for your particular encoder and it should work.
//
// NOTE: Arduinos have 2 interrupts so 2 rot encoders is the max for this code at least.
///////////////////////////////////////////////////////
// Cowen 2022. Ideas from Gianna Jordan. Ideas from these sites...
// https://www.instructables.com/Tutorial-of-Rotary-Encoder-With-Arduino/
// https://www.circuitschools.com/rotary-encoder-with-arduino-in-detail-with-example-codes/
// 
///////////////////////////////////////////////////////

#define encoder1PinA 2 // Needs to be the interrupt pin on the Arduino
#define encoder2PinA 3 // Needs to be the interrupt pin on the Arduino
#define encoder1PinB 4 // Second signal line from encoder
#define encoder2PinB 5 // Second signal line from encoder
#define outPinCWTic1 8 // Sends a signal for each CW Tic
#define outPinCCWTic1 9 // CCW
#define outPinCWTic2 10 // Sends a signal for each CW Tic
#define outPinCCWTic2 11 // 
#define outPinFullTic1 12 // Sends a pulse for each full rotation. Might be useful for calibration.
#define outPinFullTic2 13 // Sends a pulse for each full rotation.

#define TTL_DELAY_MS 2 // Duration the TTL is high. Be sure you data acquisition system can handle the delay. The rise time for arduino is in the 40ns range. More than 2ms might interrupt other processes in this code.
#define TICS_PER_SIGNAL 60 // Send a signal every xx Tics. Many acquisition systems have a hard time keeping up with the full tic rate (up to 5000 tics/second) so we only send a signal every xx tics.
#define TICS_PER_ROTATION 600 // Tics for a full 360degrees rotation.

long encoder1Pos = 0;
long encoder2Pos = 0;
volatile byte encoder1Rising = 0; // attachInterrupt requires volatile - unstable without it. (I tried it without this and it started missing tics. More precise with it.)
volatile byte encoder2Rising = 0;

int tempEncoder1Pos = 0;
int tempEncoder1PosFullRot = 0;
int tempEncoder2Pos = 0;
int tempEncoder2PosFullRot = 0;

long lastValRotary1 = 0;
long lastValRotary2 = 0;
int send_rotary_signal1 = 0;
int send_rotary_signal2 = 0;
int send_full_rot_signal1 = 0;
int send_full_rot_signal2 = 0;

unsigned long currentMillis = 0;

void setup() {
  Serial.begin(115200); // Be sure your com port is set to receive this. The high rate helps if spinning fast perhaps.
  pinMode(encoder1PinA, INPUT_PULLUP); // must be pullup
  pinMode(encoder1PinB, INPUT_PULLUP);
  pinMode(encoder2PinA, INPUT_PULLUP);
  pinMode(encoder2PinB, INPUT_PULLUP);
  
  pinMode(outPinCWTic1, OUTPUT);
  pinMode(outPinCCWTic1, OUTPUT);
  pinMode(outPinFullTic1, OUTPUT);
  pinMode(outPinCWTic2, OUTPUT);
  pinMode(outPinCCWTic2, OUTPUT);
  pinMode(outPinFullTic2, OUTPUT);

  digitalWrite(outPinCWTic1, 0);
  digitalWrite(outPinCCWTic1, 0);
  digitalWrite(outPinFullTic1, 0);
  digitalWrite(outPinCWTic2, 0);
  digitalWrite(outPinCCWTic2, 0);
  digitalWrite(outPinFullTic2, 0);
  
  attachInterrupt(digitalPinToInterrupt(2), doEncoder1, RISING); // Must be rising
  attachInterrupt(digitalPinToInterrupt(3), doEncoder2, RISING); // Must be rising

  Serial.println("completed setup.");

}

void loop() {
  if (encoder1Rising == 1){
    encoder1Rising = 0;

    if (digitalRead(encoder1PinA) != digitalRead(encoder1PinB))
    {
      encoder1Pos++;
      tempEncoder1Pos++;
      tempEncoder1PosFullRot++;
    } else {
      encoder1Pos--;
      tempEncoder1Pos--;
      tempEncoder1PosFullRot--;
    }

    if (abs(tempEncoder1Pos) >= TICS_PER_SIGNAL) {
      tempEncoder1Pos = 0;
      send_rotary_signal1 = 1;
    }

    if (abs(tempEncoder1PosFullRot) >= TICS_PER_ROTATION) {
      tempEncoder1PosFullRot = 0;
      send_full_rot_signal1 = 1;
    }

    if (send_rotary_signal1 > 0 ) {
      currentMillis = millis();
      send_rotary_signal1 = 0;
      Serial.print("A,"); // for parsing the file later, this can be used to parse out the rows for the rotary encoder in case this code is added to a larger set of code that has different serial outputs interleaved with this output.
      Serial.print(currentMillis);
      if (encoder1Pos > lastValRotary1) {
        digitalWrite(outPinCWTic1, HIGH);
        delay(TTL_DELAY_MS); // A possible alternative would be to do this asynchronously.
        digitalWrite(outPinCWTic1, LOW); // ensures the direction signal and tic overlap.   
        Serial.print(",1");
      }else if (encoder1Pos < lastValRotary1)  {
        digitalWrite(outPinCCWTic1, HIGH);
        delay(TTL_DELAY_MS); // A possible alternative would be to do this asynchronously.
        digitalWrite(outPinCCWTic1, LOW); // ensures the direction signal and tic overlap.
        Serial.print(",-1");
      }else {
        // This should rarely if ever happen.
        Serial.print(",0");
      }
      lastValRotary1 = encoder1Pos;
      
      Serial.print(",");
      Serial.print(encoder1Pos);

      if (send_full_rot_signal1 == 1) {
        send_full_rot_signal1 = 0;
        digitalWrite(outPinFullTic1, HIGH);
        delay(TTL_DELAY_MS);
        digitalWrite(outPinFullTic1, LOW);
        Serial.print(",1");
      }else{
        Serial.print(",0");
      }
      
      Serial.println();
    }
  }


  // Do the same for the second encoder (just change the 1 to a 2 in the vbl names)
   if (encoder2Rising == 1){
    encoder2Rising = 0;

    if (digitalRead(encoder2PinA) != digitalRead(encoder2PinB))
    {
      encoder2Pos++;
      tempEncoder2Pos++;
      tempEncoder2PosFullRot++;
    } else {
      encoder2Pos--;
      tempEncoder2Pos--;
      tempEncoder2PosFullRot--;
    }

    if (abs(tempEncoder2Pos) >= TICS_PER_SIGNAL) {
      tempEncoder2Pos = 0;
      send_rotary_signal2 = 1;
    }

    if (abs(tempEncoder2PosFullRot) >= TICS_PER_ROTATION) {
      tempEncoder2PosFullRot = 0;
      send_full_rot_signal2 = 1;
    }

    if (send_rotary_signal2 > 0 ) {
      currentMillis = millis();
      send_rotary_signal2 = 0;
      Serial.print("B,"); // for parsing the file later, this can be used to parse out the rows for the rotary encoder in case this code is added to a larger set of code that has different serial outputs interleaved with this output.
      Serial.print(currentMillis);
      if (encoder2Pos > lastValRotary2) {
        digitalWrite(outPinCWTic2, HIGH);
        delay(TTL_DELAY_MS); // A possible alternative would be to do this asynchronously.
        digitalWrite(outPinCWTic2, LOW); // ensures the direction signal and tic overlap.   
        Serial.print(",1");
      }else if (encoder2Pos < lastValRotary2)  {
        digitalWrite(outPinCCWTic2, HIGH);
        delay(TTL_DELAY_MS); // A possible alternative would be to do this asynchronously.
        digitalWrite(outPinCCWTic2, LOW); // ensures the direction signal and tic overlap.
        Serial.print(",-1");
      }else {
        // This should rarely if ever happen.
        Serial.print(",0");
      }
      lastValRotary2 = encoder2Pos;
           
      Serial.print(",");
      Serial.print(encoder2Pos);

      if (send_full_rot_signal2 == 1) {
        send_full_rot_signal2 = 0;
        digitalWrite(outPinFullTic2, HIGH);
        delay(TTL_DELAY_MS);
        digitalWrite(outPinFullTic2, LOW);
        Serial.print(",1");
      }else{
        Serial.print(",0");
      }
      
      Serial.println();

    }
  }
  // This is where I would put the asynchronous timer to take the place of delay 
  // if I ever become concerned about delay choking the processing of rotary encoder input.
  // e.g. if cumulative_delay1_ms > TTL_DELAY_MS then turn output pin off.

}

void doEncoder1()
{ // Only runs on rising edge
  encoder1Rising = 1;
}


void doEncoder2()
{ // Only runs on rising edge
  encoder2Rising = 1;
}

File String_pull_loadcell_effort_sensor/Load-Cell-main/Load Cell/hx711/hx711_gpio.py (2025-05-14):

# MIT License

# Copyright (c) 2019 

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
from machine import enable_irq, disable_irq, idle, Pin
import time

class HX711:
    def __init__(self, clock, data, gain=128):
        self.clock = clock
        self.data = data
        self.clock.value(False)

        self.GAIN = 0
        self.OFFSET = 0
        self.SCALE = 1

        self.time_constant = 0.25
        self.filtered = 0

        # determine the number of attempts to find the trigger pulse
        start = time.ticks_us()
        for _ in range(3):
            temp = self.data()
        spent = time.ticks_diff(time.ticks_us(), start)
        self.__wait_loop = 3_000_000 // spent

        self.set_gain(gain);

    def set_gain(self, gain):
        if gain is 128:
            self.GAIN = 1
        elif gain is 64:
            self.GAIN = 3
        elif gain is 32:
            self.GAIN = 2

        self.read()
        self.filtered = self.read()

    def conversion_done_cb(self, data):
        self.conversion_done = True
        data.irq(handler=None)

    def read(self):
        if hasattr(self.data, "irq"):
            self.conversion_done = False
            self.data.irq(trigger=Pin.IRQ_FALLING, handler=self.conversion_done_cb)
            # wait for the device being ready
            for _ in range(500):
                if self.conversion_done == True:
                    break
                time.sleep_ms(1)
            else:
                self.data.irq(handler=None)
                raise OSError("Sensor does not respond")
        else:
            # wait polling for the trigger pulse
            for _ in range(self.__wait_loop):
                if self.data():
                    break
            else:
                raise OSError("No trigger pulse found")
            for _ in range(5000):
                if not self.data():
                    break
                time.sleep_us(100)
            else:
                raise OSError("Sensor does not respond")

        # shift in data, and gain & channel info
        result = 0
        for j in range(24 + self.GAIN):
            state = disable_irq()
            self.clock(True)
            self.clock(False)
            enable_irq(state)
            result = (result << 1) | self.data()

        # shift back the extra bits
        result >>= self.GAIN

        # check sign
        if result > 0x7fffff:
            result -= 0x1000000

        return result

    def read_average(self, times=3):
        sum = 0
        for i in range(times):
            sum += self.read()
        return sum / times

    def read_lowpass(self):
        self.filtered += self.time_constant * (self.read() - self.filtered)
        return self.filtered

    def get_value(self):
        return self.read_lowpass() - self.OFFSET

    def get_units(self):
        return self.get_value() / self.SCALE

    def tare(self, times=15):
        self.set_offset(self.read_average(times))

    def set_scale(self, scale):
        self.SCALE = scale

    def set_offset(self, offset):
        self.OFFSET = offset

    def set_time_constant(self, time_constant = None):
        if time_constant is None:
            return self.time_constant
        elif 0 < time_constant < 1.0:
            self.time_constant = time_constant

    def power_down(self):
        self.clock.value(False)
        self.clock.value(True)

    def power_up(self):
        self.clock.value(False)

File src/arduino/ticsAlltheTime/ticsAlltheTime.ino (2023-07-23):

/*
 * Tracks tics and outputs distance. Only resets distance when >= tardist and laser has been tripped. 
 * 
 */

#define pinA 40
#define pinB 36
#define buttonIN 48 
#define pelout 26 
#define TTL 32
#define clockPin 22
#define signalPin 24
#define CAM 52
#define diameter 2.185 //GREEN WHEEL  Diameter of wheel on rotary encoder (inner diameter)
#define pulses 600.0 //Number of rotary encoder C pins
#include <stdio.h>
#include <digitalWriteFast.h>
//#define diameter 2.185 //cm
//#define diameter 2.525 //BLACK WHEEL
#define laser_pin 13 // pin for laser 1


/////////////////////////////////////////////////////////
//Values to be set before recording
#define feed_time 110 // 120 for EXPERIMENT && 10000 for CLEANING ONLY 
int tardist = 250; //Target Pull Distance (cm)
int probedist = 312; // Longer target pull distance for probe trials
int randomPercent = 20; // 20 for 20%. 50 for 50%. 
bool randomMode = false; // true if you want to have random mode after a certain amt of times pulled
int timesPulledThreshold = 10; // the number of times youwant rat to pull string at default amt before doing random distances
/////////////////////////////////////////////////////////


int timesPulled = 0;
int aState;
int bState;
int cState;
int aLS;
int bLS;
int rewardNo=0;
float pd;
float dist;
float ecirc;
float total_dist=0;
float BoutLength;
long chance_var;
unsigned long start;
unsigned long current;
unsigned long timeout_end;
unsigned long tics=0;
long randNumber;
int randomRange = 100/randomPercent;
bool laser_off;
int state = 1; // 0 is not counting distance since rat hasn't eaten yet. 1 is counting distance.
bool fed_already = false;

void setup() {
  //initialize rot encoder pins as input and pellet dispenser + INTAN TTL pins as output
  pinMode (pinA, INPUT);
  pinMode (pinB, INPUT);
  pinMode (buttonIN, INPUT);
  pinMode(pelout, OUTPUT);
  pinMode(CAM, OUTPUT);
  pinMode(TTL, OUTPUT);
  pinMode(signalPin, OUTPUT);
  pinMode(clockPin, OUTPUT);
  digitalWrite(pelout, LOW); // Is high open or closd
  digitalWrite(CAM, HIGH);
  pinMode (laser_pin, INPUT);
  Serial.begin(115200); //was 9600
  // print headers to file
  //Serial.println("Time,signal,distance,target distance,times pulled,random range,random number");
  Serial.println("Time,signal");
  //Calculates pull distance for each rot encoder rotation trigger, starts timer
  ecirc = 2.0 * 3.14159 * (diameter/2);
  pd = (ecirc / pulses);   //pulse distance variable
  start=millis(); 
}


/** 
 *  This is the main function of this program which tracks if the laser has been 
 *  tripped as well as tracks rotations of the rotary encoder. 
 *  Includes manual button press for feed and tracks rotary encoder for distance
 * Once the threshold distance is passed then feed is dispensed via the feed
 * function. 
 * 
*/
void loop() {

  // This allows user to press the button to manually dispense feed
  cState = digitalRead(buttonIN);
  if (cState != LOW){
    feed();
  }

  // Prints for laser on and when laser is off
  laser_off = digitalRead(laser_pin);
  if (!laser_off) {
    printData(2);
    while (!laser_off){
     // Here so l print isn't all the time
     laser_off = digitalRead(laser_pin);
    }
    printData(3);
    //resets distance once >= tardist AND laser has been tripped
    if (dist >= tardist){
      dist = 0;
      fed_already = false;
    }
  }

  //increments distance variable
  aState = digitalRead(pinA);
  if ((aState != aLS) && (aState == HIGH)){
      if (digitalRead(pinB) != aState ){            
        dist = dist + pd;
        tics++;
        if (tics==30){
            //Sends TTL Trigger to INTAN board every 30 tiks of rotary encode. 
            Serial.print(millis()); Serial.print(",");  Serial.println("t");
            //600 / 30 => every 20th turn of the encode
            digitalWriteFast(TTL, HIGH);
            delayMicroseconds(35);
            digitalWriteFast(TTL, LOW);
            tics=0;
        }
      }  
   }
   aLS = aState;
  
  // If appropriate target distance has been reached then the rat is fed
  if (dist >= tardist){
    
    //Send data point of time of  feeding
    if (!fed_already) {
      feed();
      fed_already = true;
      timesPulled = timesPulled + 1;
      if (randomMode && timesPulled > timesPulledThreshold){
        checkRandom(); 
      }
    }
  } 
}

// function to dispense food
void feed(){
  printData(1);
  digitalWrite(pelout, HIGH);
  delay(feed_time); //1.6 ml/s is time for .2ml reward
  digitalWrite(pelout, LOW);
}

void checkRandom(){
  // 1/20 times distance will be 300cm
  randNumber = random(randomRange);
  if (randNumber == 0){
    tardist = probedist; 
  }
  else {
    tardist = 208; 
    }
}

//TODO: Make clock signal so we can differentiate betweeen different TTL pulses
void printData(int message_type){
  int sendingSignal[4] = {0, 0, 0, 0};
   switch (message_type) {
    case 1:  // your hand is on the sensor
      sendingSignal[3] = 1; // 0 0 0 1
      break;
    case 2:  // your hand is close to the sensor
      sendingSignal[2] = 1; // 0 0 1 0
      break;
    case 3:  // your hand is close to the sensor
      sendingSignal[2] = 1; 
      sendingSignal[3] = 1; // 0 0 1 1
      break;
  }

  // Syncs short clk and signal   
  for (byte i = 0; i < 3; i = i+1){
    if (sendingSignal[i] == 1) {
      digitalWriteFast(signalPin, HIGH);
    }
    else{
      digitalWriteFast(signalPin, LOW);
    }
    digitalWriteFast(clockPin, HIGH);
    delayMicroseconds(35);
    digitalWriteFast(signalPin, LOW);
    digitalWriteFast(clockPin, LOW);
    delayMicroseconds(35);
  }
  //Serial.print(millis());
  //Serial.print(",");  Serial.print(message_type);
  /**
  Serial.print(",");  Serial.print(dist);
  Serial.print(",");  Serial.print(tardist);
  Serial.print(",");  Serial.print(timesPulled);
  Serial.print(",");  Serial.print(randomRange);
  Serial.print(",");  Serial.print(randNumber);
   */
  Serial.println();
  
  }
/*
192 399 597 789
207
198  
192

203 cm for 1 loop = 197.25 tics 
4.9 turns for 1 meter
1 meteer = 971.7 tics = 972
1.03 cm / tic
*/

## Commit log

2022-12-24 wrote arduino code for rot encoder. Seems to work
    [infinite_string.dxf]
2022-12-29 updated hardwaere software
    [string_frame.dxf]
2023-01-03 many fixes and made pinout guide
    [Pinouts.xlsx]
2023-01-09 it works - experiment control and updates to 2 rot encoder
2023-01-12 intagraged Gias work
    [CollectedData_Gianna.csv, Rot Encoder Wheel.SLDPRT, Rot Encoder Wheel.STL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]
2023-03-27 clock and signal code - Pin 22 and 24
    This arduino code should be able to output a signal and clock based off inputs from lazer and rotary encoder.
2023-04-04 Single rotary encoder. 2 lasers. Reset distance pulled after both lasers triggered.
    [experiment_control_V2.ino]
2023-04-07 Training
    box and platform training
    [TEMPLATE_Training_Log.xlsx, Training_Log.xlsx]
2023-04-12 - changed tic for reward to int
    Needed to be int to change between long and short distances randomly
    [experiment_control_V2.ino]
2023-04-13 Changed encoder2 to be under tics for reward 1
    Clockwise and counter clockwise should work under same constraints
2023-04-13 Laser crossed print statements
2023-04-20 training updates
    updates to training files/presentation/figs
    [Mean_Length_Day.xlsx, Training_Log.xlsx]
2025-08-20 started update for PWM output
    [1.csv, 2.csv]
